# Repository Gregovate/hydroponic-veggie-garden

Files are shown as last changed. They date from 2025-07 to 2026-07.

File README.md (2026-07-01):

# Hydroponics Veggie Garden

A modular hydroponic automation platform built around **ESPHome**, **Home Assistant**, **Node-RED**, and **MariaDB**.

The project has evolved from a simple monitoring controller into a complete hydroponic management system capable of:

* Automated reservoir refill
* Automatic nutrient dosing
* EC monitoring and reference measurements
* Historical event logging
* Seasonal crop management
* Nutrient inventory tracking
* Dashboard-based operation
* Long-term production analysis

The repository contains the firmware, automation workflows, database schema, hardware design, and engineering documentation required to operate, maintain, and rebuild the system.

---

# System Architecture

```text
ESPHome Controller
        │
        ▼
Home Assistant
        │
        ▼
Node-RED
        │
        ▼
MariaDB
        │
        ▼
Dashboard • History • Reporting
```

Each layer has a well-defined responsibility.

* **ESPHome** provides hardware monitoring and low-level control.
* **Home Assistant** provides the operator interface and configuration.
* **Node-RED** performs workflow automation and business logic.
* **MariaDB** stores the permanent operational history.

---

# Standard Operating Procedures (SOP)

Routine operating procedures are located in:

`docs/sop/`

| Procedure | Markdown | Printable PDF |
|---|:---:|:---:|
| Nutrient Solution Mixing | [View](docs/sop/hydroponics-nutrient-solution-mixing.md) | [PDF](docs/sop/hydroponics-nutrient-solution-mixing.pdf) |

---

# Engineering Documentation

The engineering manual is located in the **docs** folder.

| Document | Description |
|---|---|
| [00 – System Overview](docs/00-system-overview.md) | Overall project architecture, system objectives, and engineering philosophy. |
| [01 – Database Design](docs/01-database-design.md) | MariaDB schema, normalization, design rationale, and database architecture. |
| [02 – Season & Layout](docs/02-season-and-layout.md) | Seasonal crop layouts, planting locations, and production planning. |
| [03 – Harvest & Waste Tracking](docs/03-harvest-and-waste-tracking.md) | Harvest recording, waste tracking, and production analysis. |
| [04 – Dashboard & History Design](docs/04-dashboard-history-design.md) | Home Assistant dashboards, Hydro-History browser, and operator workflows. |
| 05 – Nutrient Management & EC Control *(In Development)* | Nutrient management strategy, EC control philosophy, and automatic dosing. |
| 06 – Monitoring & Notification System *(Planned)* | Monitoring strategy, alarms, notifications, and fault handling. |
| 07 – Nutrient Inventory Management *(Planned)* | Dry inventory, stock solutions, batch management, and forecasting. |
| 99 – Disaster Recovery *(Planned)* | Procedures to rebuild the complete system after a major hardware or software failure. |

Additional engineering documents will continue to be added as the project evolves.

---

# Standard Operating Procedures

Routine operating procedures are located in:

```text
docs/sop/
```

Current SOPs include:

* `hydroponics-nutrient-solution-mixing.md`

These documents are intended to be printable field procedures.

---

# Hardware Documentation

Controller and hardware reference documentation is located in:

```text
docs/hardware/
```

Including:

* ESP32 controller
* HX711 calibration
* Alternate pressure sensor
* Voltage divider reference

---

# Repository Layout

```text
credentials/         Local credentials (not committed)

docs/                Engineering documentation
  archive/           Historical documents
  hardware/          Hardware reference
  images/            Documentation images
  sop/               Standard operating procedures

esphome/             ESPHome firmware

hardware/            Bill of materials and enclosure information

home-assistant/
  packages/          Home Assistant packages

node-red/            Production Node-RED flows

schematic/           KiCad schematic and PCB project

sql/                 Database schema and SQL objects
```

---

# Development Philosophy

The project follows a layered architecture.

* Keep hardware logic inside ESPHome.
* Keep operator interaction inside Home Assistant.
* Keep workflow automation inside Node-RED.
* Keep long-term historical data inside MariaDB.

This separation simplifies maintenance, troubleshooting, future expansion, and disaster recovery.

---

# Disaster Recovery

One objective of this repository is complete system reproducibility.

The combination of:

* engineering documentation
* firmware
* Home Assistant packages
* Node-RED flows
* SQL schema
* hardware design files

should allow the hydroponic system to be rebuilt from scratch following a major hardware or software failure.

---

# License

See the `LICENSE` file for licensing information.

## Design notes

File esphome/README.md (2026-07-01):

# ESPHome Controller

Revision: 1.0
Last Updated: 2026-07-01
Status: Production

## Purpose

The ESPHome controller performs the real-time hydroponics control work. It directly interfaces with the sensors, relays, pumps, solenoid, and local controller logic.

Home Assistant and Node-RED supervise and log the system, but the ESPHome controller performs most of the physical control.

## Main File

| File | Purpose |
|---|---|
| `hydroponics-patio-esp32.yaml` | Active ESP32 patio controller firmware. |
| `d1mini.yaml` | Older/monitoring controller reference. |

## Responsibilities

- Read tank volume sensors
- Read water temperature
- Read EC/TDS probe voltage
- Track fill gallons
- Track dose amounts
- Control water fill solenoid
- Control nutrient Pump A
- Control nutrient Pump B
- Expose sensors and switches to Home Assistant
- Provide the physical signals used by Node-RED cycle logging

## Important Entities

| Entity | Purpose |
|---|---|
| `switch.hydroponics_patio_esp32_water_fill_solenoid` | Water fill solenoid control |
| `switch.hydroponics_patio_esp32_nutrient_pump_a` | Nutrient Part A pump |
| `switch.hydroponics_patio_esp32_nutrient_pump_b` | Nutrient Part B pump |
| `sensor.hydroponics_patio_esp32_fill_gallons` | Gallons added during fill |
| `sensor.hydroponics_patio_esp32_dose_a_ml` | Pump A dose volume |
| `sensor.hydroponics_patio_esp32_dose_b_ml` | Pump B dose volume |
| `sensor.hydroponics_patio_esp32_tds_raw` | Raw EC/TDS probe voltage |
| `sensor.hydroponics_patio_esp32_tank_temp` | Tank water temperature |
| `sensor.outside_tank_gallons` | Current tank volume |

## Downstream Consumers

| Consumer | Uses |
|---|---|
| Home Assistant | Dashboard display and control |
| Node-RED Cycle Manager | Watches switch state changes and logs fill/dose events |
| Node-RED TDS Reference | Captures probe voltage, tank volume, and water temperature |
| MariaDB | Stores permanent event and reference history |

## Change Log

| Date | Change |
|---|---|
| 2026-06-28 | Documented ESPHome controller role as the primary physical control layer. |

---

## Related Documentation

- [System Overview](../docs/00-system-overview.md)
- [Database Design](../docs/01-database-design.md)
- [ESP32 Controller Hardware](../docs/hardware/esp_32_controller_readme.md)

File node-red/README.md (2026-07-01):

# Hydroponics Node-RED Workflows

**Revision:** 1.1
**Last Updated:** 2026-07-01
**Status:** Production

---

# Purpose

Node-RED is the workflow automation engine for the hydroponic system.

It receives events from Home Assistant and ESPHome, executes multi-step business logic, validates operational data, and records permanent historical information in MariaDB.

Node-RED coordinates workflows between the operator interface, the ESPHome controller, and the MariaDB database. Physical hardware control remains the responsibility of ESPHome, while Home Assistant provides the primary operator interface.

---

# Responsibilities

Node-RED is responsible for:

- Workflow automation
- Multi-step process execution
- Database transactions
- Hydro-History generation
- Historical event formatting
- MQTT publication
- Business logic
- Operator workflow processing

Node-RED is not responsible for:

- Physical hardware control
- Dashboard presentation
- Long-term data storage

---

## Flow Inventory

| Flow File | Status | Purpose |
| --- | --- | --- |
| `Flow-1_Hydroponics_Cycle_Manager.json`  | ✅ Production | Logs fill/dose maintenance cycles from ESPHome switch activity. |
| `Flow-2_TDS_Reference.json` | ✅ Production | Logs handheld EC/TDS reference checks from the Home Assistant Measure EC popup. |
| `Flow-3_DB_History_Browser.json` | ✅ Production | Retrieves and formats Hydro-History records for Home Assistant. |
| `Flow-4_Add_Note_to_Selected_Event.json` | ✅ Production | Updates operator notes for historical records from supported database sources.  |
| `Flow-5_Insert_Field_Note.json` | ✅ Production | Creates standalone NOTE events with optional date and location metadata. |

---

## Hydroponics Cycle Manager

**Flow File:** `Flow-1_Hydroponics_Cycle_Manager.json`
**Database Target:** `maintenance_log`
**Last Updated:** 2026-06-28

### Purpose

Combines these ESPHome switch events into one maintenance cycle record:

* Water fill solenoid
* Nutrient Pump A
* Nutrient Pump B

### Rules

* Control mode comes from `input_select.hydroponics_outside_control_mode`.
* Control mode is not hardcoded in Node-RED.
* If water was added, the cycle logs as `FILL`.
* If no water was added and nutrient pumps ran, the cycle logs as `DOSE`.
* Fill + dose cycles remain `FILL`.

### 2026-06-28 Repair

Fixed bad logging where an automatic fill-and-dose cycle was incorrectly recorded as:

```text
esp-override DOSE
```

The flow now derives:

```text
mode       = Home Assistant control mode
event_type = physical cycle result
```

---

## TDS / EC Reference

**Flow File:** `Flow-2_TDS_Reference.json`
**Database Target:** `hydro_tds_reference_reading`
**Last Updated:** 2026-06-28

### Purpose

Logs handheld EC/TDS reference checks against the installed probe voltage.

This is a validation check, not a full calibration routine.

### Dashboard Entry Point

Home Assistant button:

```text
Measure EC
```

The popup captures:

* Handheld meter reading
* Meter units
* Note
* Current probe voltage
* Tank gallons
* Water temperature, when available

---

## Hydro-History Browser

**Flow File:** `Flow-3_DB_History_Browser.json`
**Database Target:** `v_hydro_recent_activity`
**Last Updated:** 2026-07-01

### Purpose

Provides the Hydro-History browser displayed in Home Assistant.

The flow retrieves operational history from MariaDB, formats the records for display, and publishes the results to Home Assistant through MQTT.

The browser supports browsing operational history from multiple database sources, creating standalone field notes, and adding operator annotations to existing historical records without requiring manual SQL queries.

### Dashboard Entry Point

Home Assistant History Browser

### Current Features

* State-driven browser updates
* Dynamic records per page
* Dynamic record offset
* Single-record forward/back navigation
* Page forward/back navigation
* Automatic SQL query generation
* MariaDB history retrieval
* MQTT publication to Home Assistant
* Multi-source history browser
* Event selection
* Operator note editing
* Standalone field note creation
* Automatic browser refresh after note save
* Water temperature display for EC reference measurements

### Home Assistant Helpers

* `input_number.hydro_history_record_offset`
* `input_number.hydro_history_records_per_page`
* `input_text.hydro_history_selected_event_id`
* `input_text.hydro_history_operator_note`
* `input_text.hydro_history_field_note`
* `input_datetime.hydro_history_field_note_datetime`
* `input_select.hydro_history_field_note_location`
* `input_button.hydro_history_save_operator_note`
* `input_button.hydro_history_create_field_note`

### MQTT Topic

```text
hydro/history/recent
```

---

## Add Note to Selected Event

**Flow File:** `Flow-4_Add_Note_to_Selected_Event.json`

**Database Targets:** `maintenance_log`, `hydro_tds_reference_reading`

**Last Updated:** 2026-07-01

### Purpose

Updates operator annotations for existing Hydro-History records.

The flow determines the source table from the selected source-aware event identifier and updates the appropriate database record.

This allows historical events from multiple database tables to be annotated from a single Home Assistant interface.

### Dashboard Entry Point

Home Assistant History Browser

### Current Features

* Reads selected source-aware event identifier
* Reads operator note from Home Assistant
* Updates `maintenance_log.operator_note`
* Updates `hydro_tds_reference_reading.operator_note`
* Clears operator note helper after save
* Automatically refreshes the Hydro-History browser

### Home Assistant Helpers

* `input_text.hydro_history_selected_event_id`
* `input_text.hydro_history_operator_note`
* `input_button.hydro_history_save_operator_note`

### Supported Record Sources

* `maintenance_log`
* `hydro_tds_reference_reading`

---

## Insert Field Note

**Flow File:** `Flow-5_Insert_Field_Note.json`

**Database Target:** `maintenance_log`

**Last Updated:** 2026-07-01

### Purpose

Creates standalone field notes that are stored as `NOTE` events in the `maintenance_log` table.

Unlike operator notes, field notes create a new historical record that can document observations, maintenance activities, weather conditions, equipment issues, or other operational events not associated with an existing history record.

### Dashboard Entry Point

Home Assistant History Browser

### Current Features

* Creates standalone `NOTE` events
* Optional event date override
* Optional location selection
* Uses current save time for timestamp
* Stores notes in `maintenance_log`
* Clears helper entities after save
* Automatically refreshes the Hydro-History browser

### Home Assistant Helpers

* `input_text.hydro_history_field_note`
* `input_datetime.hydro_history_field_note_datetime`
* `input_select.hydro_history_field_note_location`
* `input_button.hydro_history_create_field_note`

### Default Values

| Field | Default |
| ----- | --- |
| Source | `outside` |
| Device | `home_assistant` |
| Event Type | `NOTE` |
| Mode | `manual` |

---

# Planned Workflows

* Equipment issue workflow
* Maintenance completed workflow
* Event detail popup
* History filtering
* Search

---

# Revision History

| Date | Flow | Change |
| --- | --- | --- |
| 2026-07-01 | `Flow-5_Insert_Field_Note.json` | Initial production workflow. Added standalone field note creation with optional event date, location selection, automatic helper clearing, and Hydro-History browser refresh. |
| 2026-07-01 | `Flow-4_Add_Note_to_Selected_Event.json`| Initial production workflow. Added source-aware operator note updates supporting both `maintenance_log` and `hydro_tds_reference_reading`, automatic helper clearing, and Hydro-History browser refresh. |
| 2026-07-01 | `Flow-3_DB_History_Browser.json` | Completed Hydro-History browser. Added multi-source history support, source-aware event selection, EC reference integration, water temperature display, standalone field note support, and browser refresh improvements. |
| 2026-06-29 | `Flow-3_DB_History_Browser.json` | Initial Hydro-History browser. Added state-driven paging using Home Assistant helpers, MariaDB query of `v_hydro_recent_activity`, formatting, and MQTT publication for dashboard display. |
| 2026-06-28 | `Flow-1_Hydroponics_Cycle_Manager.json` | Repaired mode/event logging. Mode now comes from Home Assistant control mode. Fill+dose cycles log as `FILL`. |
| 2026-06-28 | `Flow-2_TDS_Reference.json` | Added production EC reference capture workflow from the Home Assistant Measure EC popup to MariaDB. |

---

# Navigation

## Engineering Manual

- [System Overview](../docs/00-system-overview.md)
- [Dashboard & History Design](../docs/04-dashboard-history-design.md)
- [Nutrient Management & EC Control](../docs/05-nutrient-management-and-ec-control.md)

## Component Documentation

- [ESPHome](../esphome/README.md)
- [Home Assistant Packages](../home-assistant/packages/README.md)
- [SQL](../sql/README.md)

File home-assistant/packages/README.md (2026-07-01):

# Home Assistant Packages

**Revision:** 1.1
**Last Updated:** 2026-07-01
**Status:** Production

---

# Purpose

Home Assistant is the supervisory and operator interface for the hydroponics system.

While the ESPHome controller performs most real-time control of the hardware, Home Assistant provides:

* Operator dashboards
* User controls
* Helper entities
* Configuration values
* Scripts
* SQL sensors
* Database integration
* User notifications
* Integration with Node-RED workflows

Home Assistant acts as the interface between the operator, the ESPHome controller, Node-RED, and the MariaDB database.

---

# System Architecture

```text
                    Operator
                        │
                        ▼
             Home Assistant Dashboard
                        │
        ┌───────────────┼───────────────┐
        │               │               │
        ▼               ▼               ▼
   Helper Entities   Scripts/UI     SQL Sensors
        │               │               │
        └───────────────┼───────────────┘
                        │
                        ▼
                   Node-RED
                Workflow Engine
                        │
                        ▼
                    MariaDB
                        ▲
                        │
                  ESPHome Controller
                        │
                        ▼
                 Physical Hardware
```

---

# System Ownership

| Item | Owner | Notes |
| --- | --- | --- |
| Physical sensors | ESPHome | Direct hardware interface |
| Pump and solenoid control | ESPHome | Real-time hardware control |
| Raw HX711 value | ESPHome | Load cell amplifier reading |
| Tank gallons | Home Assistant | Calculated from HX711 calibration points |
| Control mode | Home Assistant | Auto / Manual / ESP-Override |
| Dashboard helper entities | Home Assistant | Input helpers, scripts, SQL sensors and UI state |
| Workflow automation | Node-RED | Multi-step workflow execution and database logging |
| Maintenance history | MariaDB | `maintenance_log` |
| EC reference history | MariaDB | `hydro_tds_reference_reading` |
| Inventory | MariaDB | Purchases, batches and stock solutions |
| Harvest history | MariaDB | Seasonal production records |

---

# Package Inventory

| Package | Purpose | Status |
|---|---|:---:|
| `global_constants.yaml` | Shared constants used throughout the Home Assistant packages. | ✅ Production |
| `patio_system_constants.yaml` | Outdoor hydroponics system configuration and operating constants. | ✅ Production |
| `patio_controller.yaml` | Primary controller helpers, scripts, template sensors, and dashboard entities. | ✅ Production |
| `patio_dosing_controls.yaml` | Nutrient dosing controls, automatic dosing helpers, and Measure EC workflow support. | ✅ Production |
| `patio_energy_monitoring.yaml` | Electrical monitoring and power consumption. | ✅ Production |
| `db_connect.yaml` | SQL integration and MariaDB connection configuration. | ✅ Production |
| `db_history_dashboard.yaml` | Hydro-History dashboard entities and browser support. | ✅ Production |
| `batch_building.yaml` | Helper entities for nutrient batch creation and inventory workflows. | 🚧 Partial |
| `harvest_inputs.yaml` | Helper entities for seasonal harvest and waste workflows. | 🚧 Partial |
| `obsolete/` | Historical package versions retained for reference only. | ❌ Legacy |

---

# Responsibilities

Home Assistant serves as the supervisory control system and primary operator interface for the hydroponic vegetable garden.

Its responsibilities include:

---

## Operator Interface

Provide the primary interface for day-to-day operation.

Examples:

* System status dashboards
* Controller mode selection
* Manual controls
* Dashboard workflows
* Notifications
* System configuration
* System health

---

## Monitoring

Display current operating conditions.

Examples:

* Reservoir volume
* Probe voltage
* Estimated EC
* Water temperature
* Flow rates
* Fill status
* Dosing status
* Controller status
* Energy monitoring

---

## Operator Workflows

Provide user entry points into production workflows.

Current workflows include:

* Measure EC
* Hydro-History Browser
* Event annotation
* Standalone field notes

Planned workflows include:

* Nutrient batch creation
* Inventory updates
* Harvest entry
* Waste entry

---

## Helper Entities

Provide configurable values without modifying ESPHome firmware.

Examples include:

* Controller mode
* HX711 calibration points
* Target EC
* Fill thresholds
* Dashboard state
* Batch helper values
* Harvest helper values

---

## Scripts

Provide reusable dashboard actions.

Examples include:

* Measure EC
* Event annotation
* Field note entry
* Batch-building workflow
* Harvest workflow

---

## SQL Integration

Retrieve historical information from MariaDB for dashboard presentation.

Examples include:

* Recent activity
* Inventory status
* Event details
* Production statistics
* Future harvest summaries

---

## Node-RED Integration

Provide helper entities and workflow entry points used by Node-RED.

Examples include:

* Control mode
* Dashboard workflow triggers
* Measure EC
* History Browser
* Batch building
* Harvest entry

Node-RED executes workflow automation and writes permanent records to MariaDB.

---

## UI Automations

Some automations currently remain in the Home Assistant UI for:

* Testing
* Trace debugging
* Experimental workflows

Production automations should be migrated into package YAML or Node-RED whenever practical.

---

# Documentation Maintenance

This README describes the current Home Assistant package architecture.

Update this document whenever changes affect:

- Package organization
- Package responsibilities
- Helper entities
- Dashboard workflows
- SQL sensors
- Node-RED integration
- Production automations
- Package dependencies
- System ownership

Routine dashboard layout or cosmetic UI changes do not require updates unless they change system behavior or operator workflows.

---

# Revision History

| Date | Revision | Description |
|---|:---:|---|
| 2026-07-01 | 1.1 | Updated package inventory, added Hydro-History package, revised responsibilities, added navigation, and synchronized documentation with the current repository structure. |
| 2026-06-28 | 1.0 | Initial Home Assistant package architecture documentation. |

---

# Navigation

## Engineering Manual

- [System Overview](../../docs/00-system-overview.md)
- [Database Design](../../docs/01-database-design.md)
- [Dashboard & History Design](../../docs/04-dashboard-history-design.md)

## Component Documentation

- [ESPHome](../../esphome/README.md)
- [Node-RED](../../node-red/README.md)
- [SQL](../../sql/README.md)

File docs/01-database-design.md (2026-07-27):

# Hydroponics Database Design

**Revision:** 0.4
**Last Updated:** 2026-07-22
**Status:** Active Reference / Partial Implementation
---

# Purpose

The Hydroponics database is the permanent record for the outdoor hydroponic vegetable system.

This document identifies:

* What database objects currently exist
* What each object is used for
* What fields are available
* What writes data to each table
* What reads data from each table
* Which objects are production, partial, planned, or legacy

This document is the database reference.

Workflow implementation details belong in:

* `node-red/README.md`
* `home-assistant/packages/README.md`
* `docs/04-dashboard-history-design.md`

---

# Timestamp Standard

All operational timestamps in the Hydroponics database are stored in **local system time**.

The system is designed for a single physical installation and all history is viewed by the local operator.

Reasons:

- Simplifies SQL queries (`TODAY`, `THIS WEEK`, etc.)
- Dashboard times match the database without conversion
- Correlates directly with maintenance activities, photographs, weather, and inspection notes
- Eliminates unnecessary timezone conversions

UTC timestamps are not used within the Hydroponics database.

If cloud synchronization or multi-site support is implemented in the future, UTC conversion will occur during export rather than storage.

---

# Status Definitions

| Status | Meaning |
| --- | --- |
| ✅ Production | Used during normal operation. |
| 🚧 Partial | Object exists and may contain useful data, but workflow is incomplete. |
| 🧱 Database Only | Schema exists, but no finished operator workflow exists. |
| ⏳ Planned | Designed for a future workflow. |
| ❌ Legacy | Retained only for historical reference or migration review. |

---

# Current Production Workflows

| Workflow | Status | Writes To | Started From |
| --- | --- | --- | --- |
| Fill / Dose Cycle Logging | ✅ Production | `maintenance_log` | ESPHome switch activity through Node-RED |
| EC / TDS Reference Measurement | ✅ Production | `hydro_tds_reference_reading` | Home Assistant Measure EC popup through Node-RED |

---

# Current Object Inventory

## Base Tables

| Table | Status | Purpose |
| --- | --- | --- |
| `maintenance_log` | ✅ Production  | Primary operational event history for fill and dose cycles. |
| `hydro_tds_reference_reading` | ✅ Production  | Handheld EC/TDS meter checks compared to installed probe voltage. |
| `ingredients` | 🚧 Partial | Master list of dry nutrient ingredients. |
| `purchases` | 🚧 Partial | Purchase header records. |
| `purchase_items` | 🚧 Partial | Purchased ingredient line items. |
| `inventory_ledger` | 🚧 Partial | Inventory movement history. |
| `nutrient_batches` | 🚧 Partial | Nutrient stock batch headers. |
| `nutrient_batch_items` | 🚧 Partial | Ingredients used in each nutrient batch. |
| `nutrient_stock_solution` | 🚧 Partial | Part A / Part B stock solution containers. |
| `hydro_season` | ✅ Implemented | Growing season records. |
| `hydro_position` | ✅ Production  | Permanent growing positions (E1–E7 and W1–W6). |
| `hydro_crop` | ✅ Implemented | Master list of crop types (Tomato, Pepper, Eggplant, etc.). |
| `crop_variety` | ✅ Implemented | Crop variety master list linked to a crop type. |
| `hydro_season_planting` | ✅ Implemented | Assigns a crop variety to a permanent position for a growing season. |
| `hydro_harvest` | ✅ Implemented | Harvest records linked to the originating planting assignment. |
| `hydro_waste` | ✅ Implemented | Waste and crop loss records linked to the originating planting. |
| `stg_maintenance_csv` | ❌ Legacy | CSV import staging table. |
| `purchases_legacy` | ❌ Legacy | Earlier purchase table. |
| `dry_chem_purchases_legacy` | ❌ Legacy | Earlier dry chemical purchase table. |
| `nutrient_batches_legacy` | ❌ Legacy | Earlier nutrient batch table. |

## Views

| View | Status | Purpose |
| --- | --- | --- |
| `v_hydro_recent_activity` | ✅ Production / New | Timeline view combining maintenance events and EC reference readings. |
| `v_inventory_current` | 🚧 Partial | Current inventory quantity by ingredient. |
| `v_inventory_low` | 🚧 Partial | Low inventory warning view. |
| `v_inventory_ledger_detail`  | 🚧 Partial | Inventory transaction detail. |
| `v_ingredient_inventory` | 🚧 Partial | Ingredient inventory summary. |
| `v_remaining_batch_capacity` | 🚧 Partial | Estimated nutrient batches possible from remaining dry stock. |
| `v_purchase_costs_ytd` | 🚧 Partial | Year-to-date purchase costs. |
| `v_unit_cost_per_item_ytd` | 🚧 Partial | Unit cost calculations. |
| `v_batch_recipe` | 🚧 Partial | Nutrient batch recipe detail. |
| `v_nutrient_batches_detail`  | 🚧 Partial | Nutrient batch detail. |
| `v_harvests` | ⏳ Planned / Legacy Dependent | Harvest reporting view. |
| `v_harvest_summary_ytd` | ⏳ Planned / Legacy Dependent | Year-to-date harvest summary. |
| `dry_chem_purchases` | ❌ Legacy View | Old dry chemical purchase view. |
| `hydroponics_outside` | ❌ Broken Legacy View | Old view over maintenance data. Do not use. |

---

# Active Production Tables

## `maintenance_log`

**Status:** ✅ Production
**Purpose:** Primary operational event history.
**Written By:** Node-RED `Hydroponics_Cycle_Manager.json`
**Read By:** `v_hydro_recent_activity`, future history dashboard.

### Important Rule

`maintenance_log` is the active production event table.

`hydroponics_outside_events` was dropped and is no longer part of the active schema.

### Design Notes

`maintenance_log` records completed operational events for the hydroponics
controller.

Each record captures the controller state at the time the event occurred,
including water movement, nutrient additions, and engineering measurements.

Beginning with the dual-probe measurement architecture, the table stores both
raw and filtered voltages for each analog probe channel. The handheld EC meter
remains the engineering reference standard and is recorded separately in
`hydro_tds_reference_reading`.

### Columns

| Column | Type | Notes |
|---|---|---|
| `id` | int auto_increment | Primary key |
| `timestamp_utc` | datetime | UTC event timestamp (legacy compatibility) |
| `internal_time` | datetime | Local event timestamp used by dashboards |
| `source` | varchar(32) | Usually `outside` |
| `location` | varchar(64) | Usually `patio` |
| `crop` | varchar(32) | Reserved for future use |
| `variety` | varchar(64) | Reserved for future use |
| `device` | varchar(64) | Source device or workflow |
| `event_type` | enum | `FILL`, `DOSE`, `BATCH`, `PURCHASE`, `NOTE`, `HARVEST`, `ALERT` |
| `mode` | varchar(32) | Controller operating mode |
| `system_gallons` | float | System volume when event began |
| `gallons_added` | float | Water added during fill |
| `dose_a_ml` | float | Nutrient Part A added |
| `dose_b_ml` | float | Nutrient Part B added |
| `a0_raw_v_before` | float | A0 raw voltage before event |
| `a0_filtered_v_before` | float | A0 filtered voltage before event |
| `a1_raw_v_before` | float | A1 raw voltage before event |
| `a1_filtered_v_before` | float | A1 filtered voltage before event |
| `a0_raw_v_after` | float | A0 raw voltage after event |
| `a0_filtered_v_after` | float | A0 filtered voltage after event |
| `a1_raw_v_after` | float | A1 raw voltage after event |
| `a1_filtered_v_after` | float | A1 filtered voltage after event |
| `ec_before` | float | Reserved for future calculated EC |
| `ec_after` | float | Reserved for future calculated EC |
| `plant` | varchar(64) | Reserved for future use |
| `harvest_weight_g` | float | Harvest logging |
| `harvest_count` | int | Harvest logging |
| `harvest_unit` | varchar(16) | Default `item` |
| `cost_usd` | decimal(12,2) | Reserved for future use |
| `note` | text | Automatic event summary generated by Node-RED |
| `operator_note` | text | Optional operator-entered note |
| `raw_message` | text | Raw workflow payload retained for diagnostics |

### Indexes

| Index | Column |
|---|---|
| `PRIMARY` | `id` |
| `idx_ml_timestamp` | `timestamp_utc` |
| `idx_ml_source` | `source` |
| `idx_ml_location` | `location` |
| `idx_ml_event_type` | `event_type` |
| `idx_ml_crop` | `crop` |
| `idx_ml_variety` | `variety` |

### Voltage Measurement Fields

Beginning with the dual-probe engineering architecture, `maintenance_log`
stores independent measurements for each analog input channel.

Current assignments are:

| Channel | Current Assignment |
|---|---|
| **A0** | Original KEYESTUDIO analog probe |
| **A1** | DFRobot Gravity analog probe |

Each channel records both:

- Raw voltage (direct ADC measurement)
- Filtered voltage (used for controller operation and dashboard display)

For events that include post-event measurements (such as automatic fill),
both **Before** and **After** values are recorded.

Events that do not perform a delayed post-event measurement (such as individual
ESP-Override doses) may leave the **After** fields `NULL`.

### Event Notes

`maintenance_log` contains two note fields with different purposes.

#### `note`

Automatically generated by the Hydroponics Cycle Manager.

This field summarizes what occurred during the event and should normally not be edited.

Examples:

- auto FILL: added 5.11 gal water; dose A 51 mL; dose B 51 mL...
- esp-override DOSE: dose A 10 mL...
- manual NOTE: engineering observation...

#### `operator_note`

Optional operator comment added after the event.

Typical uses include:

- equipment failures
- wasted fills
- sensor problems
- calibration observations
- unusual operating conditions

Most events will have a `NULL` `operator_note`.

Example:

```text
Fill wasted due to broken recirculating pump hose clamp. Nutrients discharged
onto the patio instead of remaining in the reservoir.
```

---

## `hydro_tds_reference_reading`

**Status:** ✅ Production
**Purpose:** Stores handheld EC reference measurements synchronized with analog
probe voltages and operating conditions for calibration and engineering analysis.
**Written By:** Node-RED `TDS_Reference.json`
**Started From:** Home Assistant Measure EC popup
**Read By:** `v_hydro_recent_activity`, future EC reference dashboard.

### Design Notes

The handheld EC meter is the engineering reference standard.

Each record captures a synchronized snapshot of:

- Handheld EC measurement
- Analog probe voltages (A0 and A1)
- Water temperature
- Tank volume
- Rainfall and estimated dilution

These records are used to evaluate probe performance, develop EC estimation
models, and validate future automatic dosing algorithms.

### Handheld EC Recording Convention

The handheld reference instrument is a Bluelab Truncheon conductivity meter.

The Truncheon displays EC in discrete **0.2 EC increments** using illuminated
LEDs rather than a continuous numeric display.

To preserve additional resolution during engineering calibration:

- **Even-tenth values** (1.8, 2.0, 2.2, etc.) indicate a stable Truncheon LED
  at that EC value.

- **Odd-tenth values** (1.9, 2.1, 2.3, etc.) indicate the Truncheon was
  alternating between the adjacent even EC values and the midpoint was recorded
  by the operator.

Examples:

| Stored Value | Truncheon Indication |
|---|---|
| 1.8 | Stable at 1.8 EC |
| 1.9 | Alternating between 1.8 and 2.0 EC |
| 2.0 | Stable at 2.0 EC |
| 2.1 | Alternating between 2.0 and 2.2 EC |

This convention preserves additional engineering information without requiring
an additional database field and should be considered when evaluating EC
calibration data.

### Columns

| Column | Type | Notes |
|---|---|---|
| `id` | bigint auto_increment | Primary key |
| `captured_at` | datetime | Local reading timestamp |
| `system_key` | varchar(50) | Default `outside` |
| `a0_raw_v` | decimal(6,3) | A0 raw voltage |
| `a0_filtered_v` | decimal(6,3) | A0 filtered voltage |
| `a1_raw_v` | decimal(6,3) | A1 raw voltage |
| `a1_filtered_v` | decimal(6,3) | A1 filtered voltage |
| `meter_value` | decimal(8,2) | decimal(8,2) | Handheld EC reference. Even-tenth values indicate a stable Truncheon reading; odd-tenth values indicate midpoint interpolation between alternating adjacent LEDs. |
| `meter_units` | varchar(20) | Usually `EC` |
| `tank_gallons` | decimal(8,2) | Tank volume at measurement |
| `water_temp_f` | decimal(6,2) | Water temperature |
| `rain_total_in` | decimal(8,3) | Cumulative rainfall |
| `rain_since_last_reference_in` | decimal(8,3) | Rain since previous EC reference |
| `estimated_rain_added_gal` | decimal(8,3) | Estimated rainwater added |
| `note` | varchar(255) | Note entered during EC measurement |
| `operator_note` | varchar(255) | Later engineering annotation |

### Indexes

| Index | Column |
|---|---|
| `PRIMARY` | `id` |

### Analog Measurement Channels

Current channel assignments:

| Channel | Assignment |
|---|---|
| **A0** | Original KEYESTUDIO analog probe |
| **A1** | DFRobot Gravity analog probe |

Each EC reference captures both the raw ADC voltage and the filtered operating
voltage for each channel.

The filtered values are used by dashboards and engineering analysis, while the
raw values are retained for sensor characterization and future filter
development.

### Rainfall / Dilution Context

Rainfall can dilute the outdoor reservoir because part of the tank is exposed.

Each EC reference records cumulative rainfall at the time of the handheld
measurement. It also calculates rainfall since the previous EC reference and
estimates the amount of rainwater that entered the reservoir.

This allows EC reference measurements to be evaluated together with:

- handheld EC (engineering reference)
- A0 raw and filtered voltage
- A1 raw and filtered voltage
- water temperature
- tank volume
- rainfall since the previous EC reference
- estimated rainwater dilution

The estimated rain volume is calculated from the exposed tank opening defined
in the Home Assistant patio system constants.
---

## `purchases`

**Status:** 🚧 Partial
**Purpose:** Purchase header records for dry ingredients and supplies.
**Written By:** Manual SQL / future purchase workflow.
**Read By:** Purchase cost and inventory workflows.

### Columns

| Column | Type | Notes |
| --- | --- | --- |
| `purchase_id` | int auto_increment | Primary key |
| `order_number` | varchar(50) | Order number |
| `purchase_date` | date | Purchase date |
| `vendor` | varchar(100) | Default `Amazon` |
| `total_price_usd` | decimal(10,2) | Total purchase cost |
| `notes` | text | Notes |
| `created_at` | timestamp | Created timestamp |

### Indexes

| Index | Column |
| --- | --- |
| `PRIMARY` | `purchase_id` |

---

## `purchase_items`

**Status:** 🚧 Partial
**Purpose:** Purchased ingredient line items.
**Written By:** Manual SQL / future purchase workflow.
**Read By:** Inventory ledger and purchase cost views.

### Columns

| Column | Type | Notes |
| --- | --- | --- |
| `purchase_item_id` | int auto_increment | Primary key |
| `purchase_id` | int | Links to `purchases` |
| `ingredient_id` | int | Links to `ingredients` |
| `quantity_lb` | decimal(10,3) | Quantity in pounds |
| `quantity_g` | decimal(10,2) | Quantity in grams |
| `item_price_usd` | decimal(10,2) | Item cost |
| `notes` | text | Notes |
| `created_at` | timestamp | Created timestamp |

### Indexes

| Index | Column |
| --- | --- |
| `PRIMARY` | `purchase_item_id` |
| `purchase_id` | `purchase_id` |
| `ingredient_id` | `ingredient_id` |

---

## `inventory_ledger`

**Status:** 🚧 Partial
**Purpose:** Tracks dry ingredient inventory changes over time.
**Written By:** Manual SQL / future purchase, batch, and adjustment workflows.
**Read By:** Inventory views.

### Columns

| Column | Type | Notes |
| --- | --- | --- |
| `ledger_id` | int auto_increment | Primary key |
| `ledger_date` | date | Ledger event date |
| `ingredient_id` | int | Links to `ingredients` |
| `event_type` | enum | `PURCHASE`, `BATCH_USE`, `RECONCILIATION` |
| `source_table`  | varchar(50) | Source object name |
| `source_id` | int | Source record id |
| `delta_g` | decimal(10,2) | Inventory increase/decrease in grams |
| `notes` | text | Notes |
| `created_at` | timestamp | Created timestamp |

### Indexes

| Index | Column |
| --- | --- |
| `PRIMARY` | `ledger_id` |
| `ingredient_id` | `ingredient_id` |

---

## `nutrient_batches`

**Status:** 🚧 Partial
**Purpose:** Nutrient stock solution batch header.
**Written By:** Manual SQL / future batch-building workflow.
**Read By:** Nutrient batch views and stock solution tracking.

### Columns

| Column | Type | Notes |
| --- | --- | --- |
| `batch_id` | int auto_increment | Primary key |
| `batch_code` | varchar(50) | Unique batch code |
| `batch_date` | date | Batch date |
| `batch_part` | enum | `A` or `B` |
| `final_volume_ml` | decimal(10,2) | Default `3785.00` |
| `notes` | text | Notes |
| `created_at` | timestamp | Created timestamp |

### Indexes

| Index | Column |
| --- | --- |
| `PRIMARY` | `batch_id` |
| `batch_code` | `batch_code` |

---

## `nutrient_batch_items`

**Status:** 🚧 Partial
**Purpose:** Ingredients used in each nutrient batch.
**Written By:** Manual SQL / future batch-building workflow.
**Read By:** Batch recipe and inventory workflows.

### Columns

| Column | Type | Notes |
| --- | --- | --- |
| `batch_item_id` | int auto_increment | Primary key |
| `batch_id` | int | Links to `nutrient_batches` |
| `ingredient_id` | int | Links to `ingredients` |
| `quantity_g` | decimal(10,2) | Quantity used |
| `notes` | text | Notes |
| `created_at` | timestamp | Created timestamp |

### Indexes

| Index | Column |
| --- | --- |
| `PRIMARY` | `batch_item_id` |
| `batch_id` | `batch_id` |
| `ingredient_id` | `ingredient_id` |

---

## `nutrient_stock_solution`

**Status:** 🚧 Partial
**Purpose:** Tracks Part A and Part B stock solution container volumes.
**Written By:** Manual SQL / future batch-building and top-off workflows.
**Read By:** Future inventory and dosing dashboards.

### Columns

| Column | Type | Notes |
| --- | --- | --- |
| `stock_solution_id`  | int auto_increment | Primary key |
| `stock_part` | enum | `A` or `B` |
| `created_date` | date | Created date |
| `source_batch_code`  | varchar(50) | Source batch |
| `starting_volume_ml` | decimal(10,2) | Starting volume |
| `current_volume_ml`  | decimal(10,2) | Current volume |
| `status` | enum | `ACTIVE`, `EMPTY`, `ARCHIVED` |
| `notes` | text | Notes |
| `created_at` | timestamp | Created timestamp |

### Indexes

| Index | Column |
| --- | --- |
| `PRIMARY` | `stock_solution_id` |

---

# Season, Planting, Harvest, and Waste Tables

## `hydro_season`

**Status:** ⏳ Planned  
**Purpose:** Defines growing seasons.  
**Written By:** Future season setup workflow.  
**Read By:** Planting, harvest, waste, and production reports.

### Columns

| Column | Type | Notes |
|---|---|---|
| `season_id` | int auto_increment | Primary key |
| `system_key` | varchar(50) | Default `outside` |
| `season_year` | int | Season year |
| `season_name` | varchar(100) | Display name |
| `start_date` | date | Start date |
| `end_date` | date | End date |
| `status` | enum | `planned`, `active`, `closed`, `archived` |
| `notes` | text | Notes |
| `created_at` | datetime | Created timestamp |

### Indexes

| Index | Column |
|---|---|
| `PRIMARY` | `season_id` |
| `uq_hydro_season` | `system_key`, `season_year` |

---

## `hydro_position`

**Status:** ✅ Production  
**Purpose:** Defines the permanent physical growing positions within the hydroponics system. Position records are independent of growing seasons and remain constant over time.  
**Written By:** Initial system configuration.  
**Read By:** Season planting, harvest, waste, dashboards, and production reporting.

### Columns

| Column | Type | Notes |
|---|---|---|
| `position_id` | int auto_increment | Primary key |
| `system_key` | varchar(50) | Hydroponic system identifier. Default `outside`. |
| `channel` | varchar(20) | Growing channel (`East` or `West`) |
| `position_code` | varchar(10) | Permanent position identifier (E1–E7, W1–W6) |
| `position_number` | int | Position number within the channel |
| `flow_order` | int | Order of nutrient flow through the channel |
| `active` | tinyint(1) | Active position flag |
| `notes` | text | Optional notes |

### Relationships

Referenced by:

- `hydro_season_planting.position_id`

### Indexes

| Index | Type | Columns |
|---|---|---|
| `PRIMARY` | Primary Key | `position_id` |
| `uq_hydro_position` | Unique | `system_key`, `position_code` |

### Business Rules

- Position identifiers are permanent and never change.
- A position may participate in many growing seasons over time.
- Physical positions are assigned to seasons through `hydro_season_planting`.

---

## `hydro_crop`

**Status:** ✅ Implemented  
**Purpose:** Master list of supported crop types.  
**Written By:** Crop management workflow.  
**Read By:** Crop variety management, planting, harvest, waste, and production reporting.

### Columns

| Column | Type | Notes |
|---|---|---|
| `crop_id` | int auto_increment | Primary key |
| `crop_name` | varchar(50) | Crop type (Tomato, Pepper, Eggplant, etc.) |
| `active` | tinyint(1) | Active crop flag |
| `notes` | text | Optional notes |
| `created_at` | datetime | Record creation timestamp |

### Relationships

Referenced by:

- `crop_variety.crop_id`

### Indexes

| Index | Type | Columns |
|---|---|---|
| `PRIMARY` | Primary Key | `crop_id` |
| `uq_hydro_crop_name` | Unique | `crop_name` |

---

## `crop_variety`

**Status:** ✅ Implemented  
**Purpose:** Stores reusable crop varieties associated with a crop type.  
**Written By:** Crop management workflow.  
**Read By:** Season planting, harvest, waste, and production reporting.

### Columns

| Column | Type | Notes |
|---|---|---|
| `variety_id` | int auto_increment | Primary key |
| `crop_id` | int | References `hydro_crop` |
| `variety_name` | varchar(100) | Variety or cultivar name |
| `seed_source` | varchar(100) | Optional seed supplier or source |
| `notes` | text | Optional notes |
| `active` | tinyint(1) | Active variety flag |
| `created_at` | datetime | Record creation timestamp |

### Relationships

References:

- `hydro_crop.crop_id`

Referenced by:

- `hydro_season_planting.variety_id`

### Indexes

| Index | Type | Columns |
|---|---|---|
| `PRIMARY` | Primary Key | `variety_id` |
| `uq_crop_variety_crop_name` | Unique | `crop_id`, `variety_name` |
| `fk_crop_variety_crop` | Foreign Key | `crop_id` |

---

## `hydro_season_planting`

**Status:** ✅ Implemented  
**Purpose:** Assigns a crop variety to a permanent growing position for a specific growing season. This table forms the central relationship between seasons, positions, and crops.  
**Written By:** Planting workflow.  
**Read By:** Harvest, waste, dashboards, history, and production reporting.

### Columns

| Column | Type | Notes |
|---|---|---|
| `planting_id` | int auto_increment | Primary key |
| `season_id` | int | References `hydro_season` |
| `position_id` | int | References `hydro_position` |
| `variety_id` | int | References `crop_variety`; `NULL` for empty positions |
| `plant_count` | int | Number of plants at this position |
| `planted_date` | date | Planting date |
| `removed_date` | date | Removal date |
| `status` | enum | `planned`, `planted`, `removed`, `failed`, `empty` |
| `notes` | text | Optional notes |
| `created_at` | datetime | Record creation timestamp |

### Relationships

References:

- `hydro_season.season_id`
- `hydro_position.position_id`
- `crop_variety.variety_id`

Referenced by:

- `hydro_harvest.planting_id`
- `hydro_waste.planting_id`

### Indexes

| Index | Type | Columns |
|---|---|---|
| `PRIMARY` | Primary Key | `planting_id` |
| `uq_hydro_season_position` | Unique | `season_id`, `position_id` |
| `fk_hydro_planting_position` | Foreign Key | `position_id` |
| `fk_hydro_planting_variety` | Foreign Key | `variety_id` |

### Business Rules

- Each physical position receives one planting assignment per growing season.
- Empty positions are represented by `status = 'empty'`, `variety_id = NULL`, and `plant_count = 0`.
- Harvest and waste records always reference the planting assignment rather than storing crop, variety, season, or position independently.

---

## `hydro_harvest`

**Status:** ✅ Production  
**Purpose:** Records harvested produce from a planting assignment. Multiple harvests may be recorded for the same planting throughout the growing season.  
**Written By:** Node-RED Harvest workflow.  
**Read By:** Hydro-History, harvest reporting, production analysis, and future cost analysis.

### Columns

| Column | Type | Notes |
|---|---|---|
| `harvest_id` | int auto_increment | Primary key |
| `planting_id` | int | Required reference to `hydro_season_planting.planting_id` |
| `harvested_at` | datetime | Local harvest timestamp; defaults to the local database time |
| `harvest_count` | int nullable | Optional quantity harvested; stored as `NULL` when count was not entered |
| `harvest_unit` | varchar(20) | Unit associated with `harvest_count`; currently defaults to `item` |
| `total_weight` | decimal(10,3) nullable | Optional total harvested weight; stored as entered by the operator |
| `weight_unit` | enum | Operator-selected weight unit (lb, oz, g, kg); always populated |
| `quality` | enum nullable | Harvest classification: `good`, `mixed`, `poor`, or `waste`; the current Harvest workflow writes `good` |
| `notes` | text nullable | Optional operator note |
| `created_at` | datetime | Local record-creation timestamp; defaults to the local database time |

### Relationships

References:

- `hydro_season_planting.planting_id`

Foreign-key behavior:

- Updates to `planting_id` cascade to related harvest records.
- A planting assignment cannot be deleted while harvest records reference it.

### Indexes

| Index | Type | Columns |
|---|---|---|
| `PRIMARY` | Primary Key | `harvest_id` |
| `idx_hydro_harvest_planting` | Index | `planting_id` |
| `idx_hydro_harvest_date` | Index | `harvested_at` |

### Constraints

| Constraint | Type | Columns |
|---|---|---|
| `fk_hydro_harvest_planting` | Foreign Key | `planting_id` → `hydro_season_planting.planting_id` |

### Business Rules

- Every harvest belongs to one planting assignment.
- A planting may have multiple harvest records.
- Season, position, crop, and variety are derived through the planting assignment.
- Harvest count and harvest weight are independently optional.
- At least one of `harvest_count` or `total_weight` must be greater than zero before the workflow permits an insert.
- `harvest_unit` applies only to `harvest_count`.
- `weight_unit` applies only to `total_weight`.
- Harvest weight is stored in the unit selected by the operator; the workflow does not convert the value before insertion.
- `weight_unit` is always populated, even when `total_weight` is `NULL`, so the record has a defined unit if weight is added or edited later.
- The Harvest dashboard retains the last-selected weight unit after submission while clearing the planting, count, weight, and note fields.
- All operational timestamps are stored in local system time.

---

## `hydro_waste`

**Status:** ✅ Implemented  
**Purpose:** Records plant material or produce removed without being counted as harvested production.  
**Written By:** Waste tracking workflow.  
**Read By:** Waste reporting and production analytics.

### Columns

| Column | Type | Notes |
|---|---|---|
| `waste_id` | int auto_increment | Primary key |
| `planting_id` | int | References `hydro_season_planting` |
| `wasted_at` | datetime | Waste timestamp |
| `waste_type` | enum | Classified waste reason |
| `waste_count` | int | Quantity discarded |
| `waste_weight` | decimal(10,3) | Total discarded weight |
| `weight_unit` | enum | `lb`, `oz`, `g`, `kg` |
| `reason` | text | Optional detailed explanation |
| `notes` | text | Optional notes |
| `created_at` | datetime | Record creation timestamp |

### Relationships

References:

- `hydro_season_planting.planting_id`

### Indexes

| Index | Type | Columns |
|---|---|---|
| `PRIMARY` | Primary Key | `waste_id` |
| `fk_hydro_waste_planting` | Foreign Key | `planting_id` |
| `idx_hydro_waste_date` | Index | `wasted_at` |
| `idx_hydro_waste_type` | Index | `waste_type` |

### Business Rules

- Every waste record belongs to one planting assignment.
- Season, position, crop, and variety are derived through the planting assignment.
- Waste records complement harvest records when evaluating production efficiency.

---

## `v_hydro_recent_activity`

**Status:** ✅ Production
**Purpose:** Unified recent activity timeline for operator dashboards and engineering history.
**Source:** MariaDB View

### Source Tables

- `maintenance_log`
- `hydro_tds_reference_reading`

### Used By

- Hydroponics History Browser
- Home Assistant Recent Activity dashboard
- Node-RED history readback
- DBeaver troubleshooting
- Future reporting and dashboard development

### Design Notes

`v_hydro_recent_activity` provides a single chronological readback source for
recent hydroponics activity regardless of where the information is stored.

The view normalizes multiple production tables into a common structure so the
dashboard and History Browser can display fills, doses, EC references, notes,
harvests, and future event types without requiring separate queries.

### Time Handling

For records originating from `maintenance_log`:

- `activity_time` is sourced from `internal_time`.

For records originating from `hydro_tds_reference_reading`:

- `activity_time` is sourced from `captured_at`.

Both values represent local operator time for dashboard display.

### Measurement Display

The view exposes engineering measurement fields appropriate for each event type.

Examples include:

- FILL
  - Water added
  - Dose A
  - Dose B
  - A0 Filtered Before → After
  - A1 Filtered Before → After

- DOSE
  - Dose A and/or Dose B
  - A0 Filtered Before
  - A1 Filtered Before

- EC_REFERENCE
  - Handheld EC
  - A0 Filtered
  - A1 Filtered
  - Tank gallons
  - Water temperature

The view intentionally exposes filtered voltages for operator display while raw
analog measurements remain available in the underlying production tables for
engineering analysis.

---

# Views

Views provide simplified readback for dashboards, reporting, and troubleshooting.

Views are not source data. Permanent records belong in the underlying base
tables.

## Operator History

### `v_hydro_recent_activity`

**Status:** ✅ Production  
**Purpose:** Provides the unified chronological activity feed used by the
Hydro-History dashboard.

The view combines supported operational records into one operator-facing
timeline. Applications should use this view whenever a chronological history
display is required rather than querying the underlying source tables
individually.

**Primary Consumers:**

- Home Assistant Hydro-History dashboard
- Node-RED history refresh workflow
- Operator troubleshooting and event review

**Important Rule:**

`v_hydro_recent_activity` is the authoritative readback interface for the
operator activity timeline. The underlying base tables remain the authoritative
source records.

---

## Inventory and Purchasing Views

| View | Status | Purpose |
|---|---|---|
| `v_inventory_current` | 🚧 Partial | Calculates the current quantity of each dry ingredient from inventory ledger activity. |
| `v_inventory_low` | 🚧 Partial | Identifies ingredients below their configured inventory threshold. |
| `v_inventory_ledger_detail` | 🚧 Partial | Provides inventory ledger entries with ingredient names and related detail. |
| `v_ingredient_inventory` | 🚧 Partial | Provides an ingredient-level inventory summary. |
| `v_remaining_batch_capacity` | 🚧 Partial | Estimates the number of nutrient batches that can be produced from current inventory. |
| `v_purchase_costs_ytd` | 🚧 Partial | Summarizes purchase costs for the current year. |
| `v_unit_cost_per_item_ytd` | 🚧 Partial | Calculates year-to-date unit costs from purchase records. |

---

## Nutrient Batch Views

| View | Status | Purpose |
|---|---|---|
| `v_batch_recipe` | 🚧 Partial | Provides the ingredient recipe for each nutrient batch. |
| `v_nutrient_batches_detail` | 🚧 Partial | Provides detailed nutrient batch records with ingredient information. |

---

## Production Reporting Views

| View | Status | Purpose |
|---|---|---|
| `v_harvests` | ⏳ Planned | Provides harvest records with derived season, position, crop, and variety information. |
| `v_harvest_summary_ytd` | ⏳ Planned | Summarizes current-year harvest production by crop and variety. |

The production views must be rebuilt against the normalized relationship:

```text
hydro_crop
    → crop_variety
        → hydro_season_planting
            → hydro_harvest
```

# Workflow Ownership Map

This section identifies the subsystem responsible for initiating and processing
each database-writing workflow.

The database is the permanent system of record. Home Assistant provides the
operator interface, ESPHome performs physical equipment control, and Node-RED
owns workflow validation, database writes, history refresh, and completion
notifications unless otherwise documented.

| Workflow | Initiated By | Processing Owner | Database Objects | Status |
|---|---|---|---|---|
| Fill / Dose Cycle Logging | ESPHome equipment state changes | Node-RED `Hydroponics_Cycle_Manager.json` | `maintenance_log` | ✅ Production |
| EC / TDS Reference Measurement | Home Assistant Measure EC form | Node-RED `TDS_Reference.json` | `hydro_tds_reference_reading` | ✅ Production |
| Equipment Event Entry | Home Assistant dashboard | Node-RED | `maintenance_log` | ⏳ Planned |
| Dry Ingredient Purchase | Home Assistant dashboard | Node-RED | `purchases`, `purchase_items`, `inventory_ledger` | ⏳ Planned |
| Inventory Adjustment | Home Assistant dashboard | Node-RED | `inventory_ledger` | ⏳ Planned |
| Nutrient Batch Building | Home Assistant dashboard | Node-RED | `nutrient_batches`, `nutrient_batch_items`, `inventory_ledger`, `nutrient_stock_solution` | ⏳ Planned |
| Stock Solution Top-Off | Home Assistant dashboard | Node-RED | `nutrient_stock_solution` | ⏳ Planned |
| Crop Management | Home Assistant dashboard | Node-RED | `hydro_crop`, `crop_variety` | ⏳ Planned |
| Season Setup | Home Assistant dashboard | Node-RED | `hydro_season` | ⏳ Planned |
| Planting Assignment | Home Assistant dashboard | Node-RED | `hydro_season_planting` | ⏳ Planned |
| Harvest Entry | Home Assistant dashboard | Node-RED | `hydro_harvest` | ⏳ Planned |
| Waste Entry | Home Assistant dashboard | Node-RED | `hydro_waste` | ⏳ Planned | | ⏳ Planned |

---

# Current Development Priorities

The database schema is largely complete.

Future development should focus on implementing operator workflows rather than adding new tables.

Current priorities are:

1. History Dashboard
2. Equipment Event Entry
3. Dry Ingredient Purchase Workflow
4. Nutrient Batch Building
5. Stock Solution Inventory Management
6. Inventory Adjustment Workflow
7. Season Setup
8. Planting Assignment
9. Harvest Entry
10. Waste Entry

---

# Revision History

| Date | Revision | Description |
|---|---|---|
| 2026-07-22 | 0.4 | Refactored the engineering measurement model to support dual analog probe channels (A0/A1). Updated `maintenance_log`, `hydro_tds_reference_reading`, and `v_hydro_recent_activity` documentation to replace legacy single-probe terminology with raw and filtered voltage measurements. Expanded view documentation, clarified engineering data ownership, and documented the production readback architecture. |
| 2026-07-01 | 0.3 | Added `water_temp_f` and `operator_note` to `hydro_tds_reference_reading`. Updated Hydro-History design to support annotations on EC reference records and unified history browsing across multiple activity sources. |
| 2026-07-01 | 0.3 | Added Hydro-History browser support, documented operator notes, clarified the project timestamp standard, updated `v_hydro_recent_activity` to use local event time for dashboard readback, and corrected timestamp documentation for production workflows. |
| 2026-06-28 | 0.2 | Reorganized the document into a database reference. Added object inventory, table documentation, views, workflow ownership, and development priorities. Updated to reflect `maintenance_log` as the production event table after retirement of `hydroponics_outside_events`. |

---

## Navigation

**Previous:** [00 – System Overview](00-system-overview.md)

**Next:** [02 – Season & Layout](02-season-and-layout.md)

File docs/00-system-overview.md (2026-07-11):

# Hydroponics Veggie Garden System Overview

**Revision:** 1.0
**Last Updated:** 2026-06-28
**Project Status:** Active Development

---

# Purpose

The Hydroponics Veggie Garden project is an outdoor hydroponic vegetable production system designed to automate nutrient management while collecting long-term operational and crop production data.

The project began as a simple water level monitor using a Wemos D1 Mini and has evolved into a complete monitoring, automation, and data collection platform consisting of:

* ESPHome firmware
* Home Assistant
* Node-RED
* MariaDB
* KiCad hardware design
* Engineering documentation

The long-term objective is to reduce manual maintenance while improving crop production through measurement, automation, and historical analysis.

---

# System Objectives

The system is designed to:

* Monitor reservoir volume
* Automatically refill the nutrient tank
* Maintain nutrient concentration (EC)
* Monitor system flow rates
* Record maintenance and operational events
* Track nutrient inventory
* Track seasonal crop layouts
* Record harvests and waste
* Calculate production costs
* Analyze long-term system performance

Rather than simply automating pumps, the project is intended to become a complete hydroponic crop management system.

---

# Major Components

## ESPHome Controller

The ESP32 controller performs the real-time monitoring and control functions.

Major functions include:

* Reservoir volume measurement (HX711 load cells)
* Water temperature monitoring
* Flow monitoring
* Pump control
* Solenoid valve control
* EC/TDS probe monitoring
* Local safety logic
* Communication with Home Assistant

The controller is intentionally responsible only for low-level hardware control.

---

## Home Assistant

Home Assistant provides the operational user interface.

Responsibilities include:

* Dashboard presentation
* User configuration
* Manual controls
* Notifications
* Helper entities
* Automation coordination
* Device status

The dashboard is designed for day-to-day operation rather than engineering diagnostics.

---

## Node-RED

Node-RED performs higher-level automation and data processing.

Current responsibilities include:

* Nutrient dosing logic
* Event logging
* EC reference capture
* Database writes
* Inventory calculations
* Batch management

As the project grows, Node-RED will become the primary workflow engine.

---

## MariaDB

MariaDB serves as the permanent historical record for the system.

The database stores:

* Fill events
* Dosing events
* EC reference measurements
* Nutrient inventory
* Stock solution batches
* Seasonal planting information
* Harvest data
* Waste tracking
* Operational history

The database allows long-term analysis that cannot be performed using Home Assistant history alone.

---

# Project Organization

The repository is organized into several major components.

| Folder | Purpose |
| --- | --- |
| docs | Engineering documentation |
| esphome | ESPHome firmware |
| home-assistant | Home Assistant packages |
| node-red | Automation flows |
| sql | Database schema and supporting SQL |
| hardware | BOM and enclosure documentation |
| schematic | KiCad schematic and PCB files |

---

# Engineering Philosophy

The project is designed around a layered architecture.

```
Hardware
        │
        ▼
ESPHome
        │
        ▼
Home Assistant
        │
        ▼
Node-RED
        │
        ▼
MariaDB
        │
        ▼
Analysis & Reporting
```

Each layer has a clearly defined responsibility.

Keeping responsibilities separated makes the system easier to maintain and expand.

## Home Assistant Package Organization

Home Assistant packages are organized by **functional responsibility** rather than by entity type.

Each package owns a specific portion of the hydroponic system and should contain
the helpers, template entities, sensors, automations, and supporting logic
required for that responsibility.

### patio_system_constants.yaml

Owns the physical characteristics and operating parameters of the patio
hydroponic system.

Examples include:

- Tank capacity and operating limits
- HX711 calibration
- Flow calibration
- Pump calibration
- Auto-fill operating parameters
- System-specific constants

These values describe the physical system and may differ for each hydroponic
installation.

### patio_dosing_controls.yaml

Owns the routine nutrient maintenance strategy.

Examples include:

- Maintenance dose thresholds
- Target and hard-stop voltages
- Maximum maintenance step size
- Inventory lockout limits
- Maintenance timing
- Maximum maintenance cycles
- Automatic nutrient dosing logic

Separating system constants from dosing control allows future hydroponic
controllers, such as a basement system, to maintain independent hardware
configuration while reusing the same nutrient management architecture.

---

# Future Development

Current development is focused on expanding the system from automation into production management.

Major planned capabilities include:

* Seasonal crop management
* Plant position tracking
* Harvest recording
* Waste recording
* Production cost analysis
* Yield by variety
* Yield by channel position
* Nutrient consumption analysis
* Predictive inventory management
* Dashboard history and reporting

The long-term goal is to understand not only **how** the hydroponic system operates, but **why** certain growing conditions produce better results.

---

# Related Documentation

This document provides the overall project overview.

Additional documentation describes specific portions of the system.

| Document | Description |
|---|---|
| [01 – Database Design](01-database-design.md) | Database schema, normalization, and engineering philosophy. |
| [02 – Season & Layout](02-season-and-layout.md) | Seasonal crop layouts and planting locations. |
| [03 – Harvest & Waste Tracking](03-harvest-and-waste-tracking.md) | Harvest recording, waste tracking, and production analysis. |
| [04 – Dashboard & History Design](04-dashboard-history-design.md) | Dashboard philosophy, Hydro-History, and operator workflows. |
| 05 – Nutrient Management & EC Control *(In Development)* | Automatic nutrient management, EC control strategy, and dosing workflows. |
| 06 – Monitoring & Notification System *(Planned)* | System monitoring, alarms, and notification strategy. |
| 07 – Nutrient Inventory Management *(Planned)* | Dry inventory, stock solution inventory, and batch management. |
| [ESP32 Controller](hardware/esp_32_controller_readme.md) | ESP32 controller hardware and firmware overview. |
| [HX711 Calibration](hardware/calibration-process-hx711.md) | Tank calibration procedure using Home Assistant interpolation. |
| [Alternate Pressure Sensor](hardware/alternate-pressure-sensor.md) | Alternative tank level sensing using a pressure transducer. |
| [Voltage Divider Reference](hardware/voltage_divider_explained.md) | Analog input protection and voltage divider design. |
| [Nutrient Solution Mixing SOP](sop/hydroponics-nutrient-solution-mixing.md) | Printable procedure for preparing Part A and Part B stock solutions. |

---

# Revision History

| Date | Revision | Description |
| --- | --- | --- |
| 2026-06-28 | 1.0 | Initial system overview documenting the transition from a controller project to a complete hydroponic crop management platform. |

---

## Navigation

**Next:** [01 – Database Design](01-database-design.md)

**Related:**

- [ESP32 Controller](hardware/esp_32_controller_readme.md)
- [HX711 Calibration](hardware/calibration-process-hx711.md)
- [Nutrient Solution Mixing SOP](sop/hydroponics-nutrient-solution-mixing.md)

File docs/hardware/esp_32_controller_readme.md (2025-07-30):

# Hydroponics ESP32 Full Control System

This document describes the full-featured **ESP32-based hydroponics controller** as part of the Hydroponic Veggie Garden project. This version expands upon the D1 Mini monitoring build to add **automated control**, **ADC sensor support**, and **multiple operational modes** for complete system management.

---

## 🚀 Key Features

- **Three control modes** (Manual Fill, Auto Fill, Bypass)
- Dual **flow sensors** to verify flow integrity
- **HX711 load cell** for real-time tank weight monitoring
- **DS18B20** temperature sensor for water temperature
- **Optional pressure sensor** via ADC (3.3V range)
- **TDS/EC sensor support** via ESP32 analog input
- **Relay control** for:
  - Water fill solenoid
  - Nutrient dosing pump A
  - Nutrient dosing pump B
- Home Assistant integration via MQTT or native API

---

## 🧭 Modes of Operation

### 1. Manual Fill
- User-initiated tank refill
- Dosing logic based on measured refill volume
- Manual logging timestamps and quantities

### 2. Auto Fill
- Automatically triggers refill when tank level drops
- Initiates nutrient dosing cycle after fill
- Flow sensors and weight confirm successful execution

### 3. Bypass Mode
- All automated control disabled
- Useful for maintenance or troubleshooting

---

## 📐 Calibration Strategy

This version uses a **Home Assistant template sensor** to convert raw HX711 values into gallons. This method offers:

- **No need to reflash the microcontroller** when calibrating
- **6-point calibration system** stored in Home Assistant inputs
- Emergency backup calibration with a **5-gallon bucket**
- Offset tare value managed by a Home Assistant `input_number`

Template sensors and automation logic are documented in:
[home-assistant/patio-calibration.yaml](https://github.com/Gregovate/hydroponic-veggie-garden/blob/main/home-assistant/patio-calibration.yaml)

See detailed explanation: [docs/calibration-explained.md](https://github.com/Gregovate/hydroponic-veggie-garden/blob/main/docs/calibration-explained.md)

---

## 📎 ESPHome Configuration

The full working configuration for the ESP32 is stored at:
[esphome/hydroponics-patio-esp32.yaml](https://github.com/Gregovate/hydroponic-veggie-garden/blob/main/esphome/hydroponics-patio-esp32.yaml)

This includes:
- ADC logic for pressure and TDS sensors
- Switch and GPIO mapping
- Flow sensor calibration constants
- Dallas sensor address and pinout
- Web server, captive portal, and OTA support

---

## 📷 Image Assets
Visual reference images and wiring diagrams are in the
[docs/images](https://github.com/Gregovate/hydroponic-veggie-garden/tree/main/docs/images) folder.

---

## 📄 License

This project is provided under a custom personal-use license:

> "For non-commercial use only. All rights reserved."
>
> Engineering Innovations, LLC  
> Greg Liebig — https://engrinnovations.com

---

## 📚 Related Documents

- [README.md (D1 Mini version)](https://github.com/Gregovate/hydroponic-veggie-garden/blob/main/README.md)
- [Calibration Explained](https://github.com/Gregovate/hydroponic-veggie-garden/blob/main/docs/calibration-explained.md)
- [ESP32 Configuration YAML](https://github.com/Gregovate/hydroponic-veggie-garden/blob/main/esphome/hydroponics-patio-esp32.yaml)
- [Images and Diagrams](https://github.com/Gregovate/hydroponic-veggie-garden/tree/main/docs/images)

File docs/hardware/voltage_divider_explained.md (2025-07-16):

# Understanding the Voltage Divider

This guide explains how a voltage divider works, specifically in the context of safely reducing a 5V sensor signal to 3.3V (or lower) for an ESP32 or ESP8266 analog input.
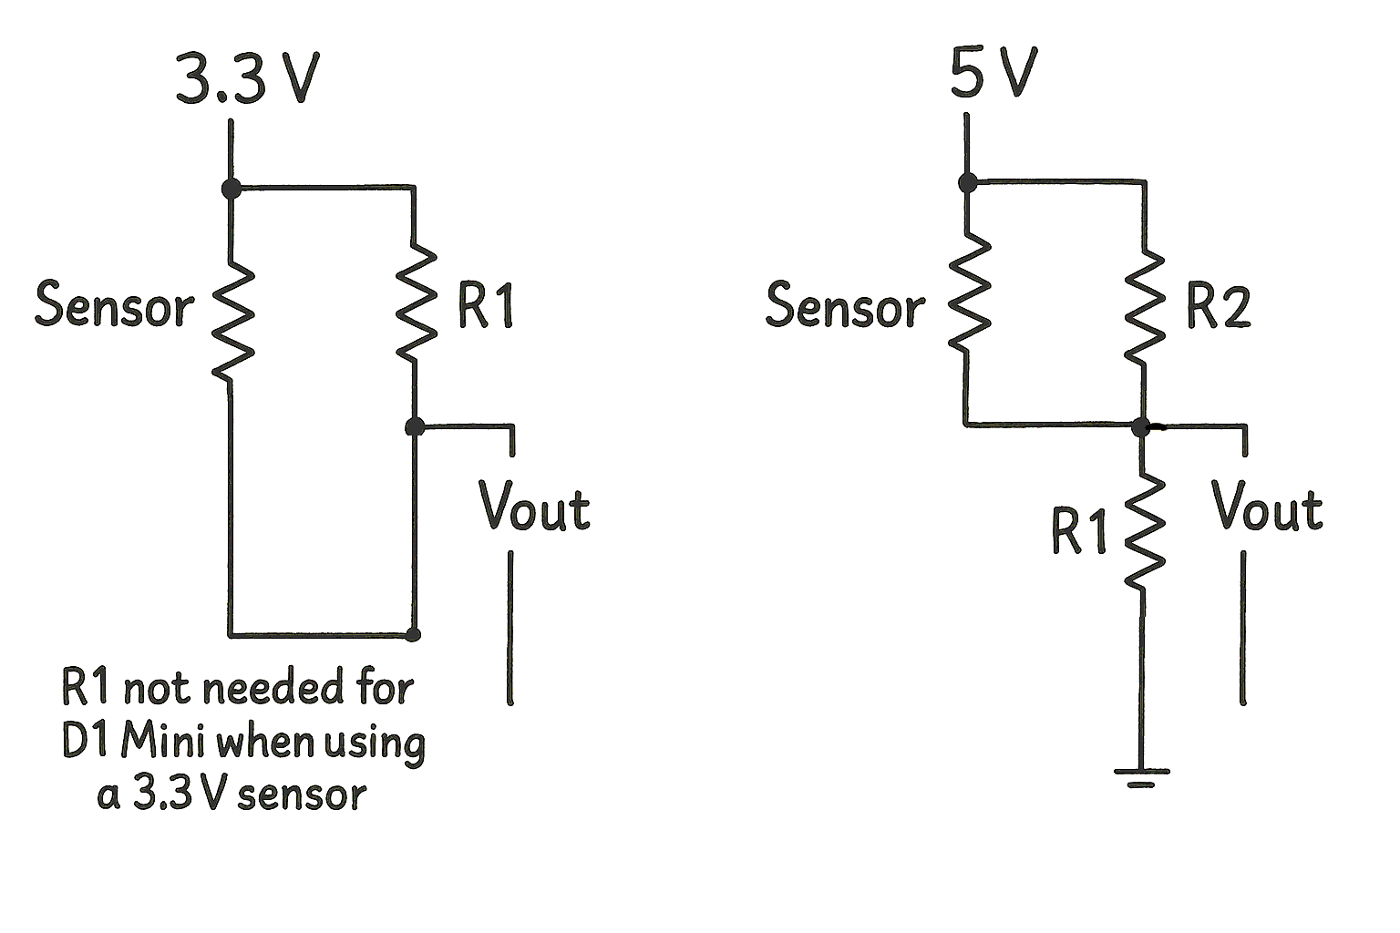
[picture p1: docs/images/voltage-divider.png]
Voltage Divider


---

## Purpose

Some analog sensors output a voltage in the range of 0–5V. However:

- The **ESP32** ADC input only tolerates up to **3.3V**
- The **ESP8266 (D1 Mini)** ADC pin (`A0`) tolerates only **0–1.0V**

Connecting a 5V signal directly to these analog inputs can **permanently damage the microcontroller**. A **voltage divider** solves this by scaling down the voltage using just two resistors.

---

## How It Works

A voltage divider is a simple circuit made from two resistors:

```
      Sensor Output (5V)
         |
        R2
         |
        +----> Vout (to analog input)
         |
        R1
         |
        GND
```

The formula for the output voltage is:

```
Vout = Vin * (R1 / (R1 + R2))
```

Where:

- **Vin** is the sensor voltage (e.g. 5V)
- **R1** is the resistor from the middle point to ground
- **R2** is the resistor from Vin to the middle point

---

## Example: Scaling 5V to \~3.3V

Let’s say the sensor outputs up to **5V**, and we want **Vout ≈ 3.3V**.

Choose:

- **R2 = 10kΩ** (top resistor)
- **R1 = 5.1kΩ** (bottom resistor)

Then:

```
Vout = 5 * (5.1 / (10 + 5.1)) ≈ 3.3V
```

This is perfect for safe use with the ESP32’s ADC.

---

## For ESP8266 (A0 Only Allows 1.0V)

If you're using a D1 Mini (ESP8266), you'll need **further voltage reduction**. Here’s one working pair:

- **R2 = 100kΩ**
- **R1 = 20kΩ**

Result:

```
Vout = 5 * (20 / 120) ≈ 0.83V (safe for A0)
```

---

## Notes

- Use precision resistors (±1% tolerance if available)
- Always connect sensor ground to the ESP ground
- You can use any resistor values as long as their **ratio** gives the correct output
- Keep resistor values reasonably high (to avoid unnecessary power draw)

---

## Summary

- A voltage divider is essential when using 5V analog sensors with 3.3V (or 1.0V) microcontrollers.
- Two resistors scale the signal safely to the desired range.
- The resistor values you choose depend on your target voltage and the microcontroller’s limits.

By wiring your voltage divider as shown above and selecting the correct resistor pair, you can safely read tank level data from a 5V sensor using ESPHome. Just be sure to check your voltages before connecting to your micro controller!

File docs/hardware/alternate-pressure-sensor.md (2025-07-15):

**Using a Submersible Liquid Level Pressure Sensor with ESPHome**

This guide explains how to replace an HX711 load cell system with a submersible hydrostatic pressure sensor (e.g., 1m range, 5m cable) for use with ESPHome on an ESP8266 (D1 Mini) or ESP32 Mini board.

---

## 1. Overview

Submersible liquid level sensors measure pressure at the bottom of a tank and convert it to voltage. This voltage is proportional to the liquid height. These sensors are ideal for large tanks where load cells are impractical.

---

## 2. Typical Sensor Wiring

Most submersible hydrostatic sensors have three wires:

| Wire Color | Function |
| --- | --- |
| Red | VCC (typically 5V) |
| Black | GND |
| Yellow | Analog Signal (0-5V) |

**Note:** Confirm your sensor's wiring and voltage range before connecting.

---

## 3. Using with D1 Mini (ESP8266)

### ⚠ Important:

- The ESP8266 analog pin (A0) only accepts **0–1.0V**.
- Most sensors output **0–5V**, so a voltage divider is required.

### Voltage Divider Example (5V to 1V):

Use two resistors:

- R1 = 20kΩ (connects sensor output to A0)
- R2 = 5kΩ (connects A0 to GND)

This reduces 5V to 1V at full scale:

```
Vout = Vin * (R2 / (R1 + R2)) = 5V * (5k / 25k) = 1V
```

### Wiring Table:

| Sensor Wire | Connects To |
| --- | --- |
| Red | 5V (D1 Mini VCC or external) |
| Black | GND |
| Yellow | Voltage divider → A0 |

---

## 4. Using with Mini ESP32

- The ESP32 supports **true 0–3.3V** analog readings on many ADC pins (e.g., GPIO34, GPIO35).
- No voltage divider is needed if the sensor outputs **≤3.3V**.
- If using a 5V output sensor, **a voltage divider is still required**.

### ESP32 Example Wiring (Sensor outputs 0–3.3V):

| Sensor Wire | Connects To |
| --- | --- |
| Red | 5V or 3.3V (check spec) |
| Black | GND |
| Yellow | GPIO34 |

---

## 5. ESPHome Configuration

### For D1 Mini (A0):

```yaml
sensor:
  - platform: adc
    pin: A0
    name: "Tank Pressure (Raw)"
    update_interval: 10s
    filters:
      - calibrate_linear:
          - 0.10 -> 0    # Voltage at empty
          - 0.90 -> 40   # Voltage at full (in inches, cm, etc.)
    unit_of_measurement: "in"
    id: tank_level_sensor
```

### For ESP32 (GPIO34):

```yaml
sensor:
  - platform: adc
    pin: GPIO34
    name: "Tank Pressure (Raw)"
    update_interval: 10s
    attenuation: 11db  # Enables full 3.3V range
    filters:
      - calibrate_linear:
          - 0.1 -> 0
          - 2.5 -> 40
    unit_of_measurement: "in"
    id: tank_level_sensor
```

### Convert to Gallons (Template Sensor):

```yaml
  - platform: template
    name: "Tank Gallons"
    unit_of_measurement: "gal"
    lambda: |-
      return id(tank_level_sensor).state * 5.1;  // Replace with correct factor
    update_interval: 10s
```

---

## 6. Benefits and Limitations

### Benefits:

- No weight limitation (great for 200+ gallon tanks)
- Simple installation (drop-in sensor)
- Fewer moving parts

### Limitations:

- Requires analog input
- Must calibrate accurately
- Some sensors require 12V (check datasheet)

---

## 7. Summary

| Feature | HX711 Load Cell | Submersible Pressure Sensor  |
| --- | --- | --- |
| Measures | Weight | Water pressure (height) |
| ESP Pin Type | Digital (HX711) | Analog (ADC) |
| Calibration Complexity | Moderate | Easy with `calibrate_linear` |
| Best Use Case | Small tanks, precise | Large tanks (e.g., 200 gal)  |

---

For tanks too large to be measured accurately with a platform scale, this hydrostatic solution offers a clean, scalable, and ESPHome-compatible option.

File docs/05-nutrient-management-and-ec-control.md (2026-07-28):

# Nutrient Management and EC Control

Revision: 0.3
Last Updated: 2026-07-20
Status: Draft

---

# Purpose

This document describes the nutrient management strategy used by the hydroponic vegetable garden.

It documents how nutrient concentration is measured, maintained, validated, and recorded while defining the engineering philosophy behind automatic nutrient dosing, long-term EC control, and controller operation.

This document focuses on **maintaining nutrient concentration within the hydroponic reservoir**.

Preparation of nutrient stock solutions, inventory management, purchasing, batch preparation, and inventory tracking are documented separately in **07 – Nutrient Inventory Management**.

Unlike the nutrient stock solution mixing procedure, this document focuses on **system operation** rather than chemical preparation.

---

# Design Goals

The nutrient management system is intended to:

- Maintain healthy nutrient concentrations.
- Automatically replace nutrients lost during refill events.
- Maintain nutrient concentration during normal circulation.
- Prevent over-dosing.
- Record all nutrient additions.
- Validate sensor performance using independent handheld and installed sensor measurements.
- Compare multiple installed conductivity sensors under identical operating conditions.
- Support long-term calibration and evaluation of installed conductivity sensors.
- Separate raw conductivity measurement from calculated EC estimation.
- Build a historical database for long-term engineering analysis and future controller improvements.
- Preserve lifetime nutrient usage without resetting cumulative dosing totals.
- Provide reliable controller state information for operator awareness.
- Support future improvements to automatic nutrient dosing algorithms.

**Inventory management, nutrient batch preparation, and chemical purchasing are documented separately in
[07 – Nutrient Inventory Management](07-nutrient-inventory-management.md).**

---

# Nutrient Management Philosophy

The nutrient management system is designed to maintain healthy nutrient
concentrations while minimizing operator intervention and preventing
over-dosing.

Unlike traditional hydroponic controllers that rely on calibrated EC probes and
PID control, this system uses a staged engineering approach centered around a
continuously monitored analog conductivity probe, periodic handheld EC
validation, and conservative proportional maintenance dosing.

## Design Objectives

The controller is intended to:

- Maintain stable nutrient concentration during normal operation.
- Automatically replace nutrients added during refill events.
- Gradually restore nutrient concentration during circulation when EC declines.
- Prevent excessive nutrient additions.
- Record every nutrient addition for historical analysis.
- Continuously improve probe calibration using field data.

## Configurable Maintenance Timing

Routine maintenance dosing uses several configurable timing parameters to allow
the controller behavior to be tuned without modifying automation logic.

### Maintenance Debounce

Defines how long the probe voltage must remain below the maintenance threshold
before a maintenance dose cycle is permitted to begin.

This prevents transient voltage changes from initiating unnecessary nutrient
corrections.

### Mixing Time

Defines how long the circulation system is allowed to mix newly added nutrients
before the post-dose TDS measurement is evaluated.

This value may require adjustment if tank volume or circulation flow rates are
changed.

### Next Maintenance Dose Offset

Defines the minimum time that must elapse after completion of the mixing period
before another automatic maintenance dose may begin.

This provides a short stabilization period between consecutive maintenance dose
cycles while allowing the controller to continue correcting nutrient levels if
required.

### Maximum Maintenance Cycles

Defines the maximum number of consecutive automatic maintenance correction
cycles permitted during a single maintenance event.

This prevents repeated nutrient additions caused by abnormal sensor behavior or
unexpected system faults while still allowing gradual correction toward the
target operating range.

## Fill-Based Nutrient Replacement

Whenever water is added to the system, the controller measures the actual gallons
added.

The patio_controller automatically calculates the required Part A and Part B
nutrient additions using the configured nutrient ratio and injects both parts
without operator intervention.

This provides repeatable nutrient replacement after every fill event.

---

# Nutrient Inventory Management

## Design Philosophy

The nutrient management system maintains an estimated inventory of nutrient
solution at two levels:

- Production nutrient containers connected directly to the dosing pumps.
- Backup nutrient containers used to replenish the production containers.

The objective is to maintain sufficient inventory accuracy for normal operation,
batch planning, and chemical purchasing. Laboratory precision is not required.
Small estimation errors are acceptable and may be corrected periodically through
manual inventory adjustment.

## Production Inventory

The controller maintains an estimated inventory for each production nutrient
container.

Production inventory decreases automatically whenever the nutrient dosing pumps
operate.

Production inventory increases only when nutrient is transferred from the
corresponding backup container.

## Backup Inventory

The controller maintains an estimated inventory for each backup nutrient
container.

Backup inventory increases only when a new nutrient batch is prepared.

Backup inventory decreases whenever nutrient is transferred into a production
container.

To preserve recipe consistency, new nutrient batches are prepared only after the
corresponding backup container has been emptied. Existing nutrient is never
mixed with a newly prepared batch.

## Production Refill Workflow

The operator's goal is to refill each production container to its nominal full
capacity of **3780 mL (1 US gallon)** whenever sufficient nutrient exists in the
backup container.

The controller determines:

- Current production inventory.
- Current backup inventory.
- Quantity required to refill the production container.

If sufficient nutrient exists in the backup container, the production container
is refilled to full capacity.

If insufficient nutrient remains, all remaining nutrient is transferred from the
backup container into the production container. The backup inventory then
becomes zero.

The refill workflow automatically updates:

- Production inventory.
- Backup inventory.
- Production refill baseline.
- Maintenance history.

Cumulative nutrient usage is never reset during this process.

## Batch Preparation

Preparing a new nutrient batch replenishes only the corresponding backup
container.

Batch preparation history, formulation information, and cost records remain
independent of operational inventory tracking.

## Manual Inventory Adjustment

Estimated inventory is considered sufficiently accurate for normal operation.

If desired, the operator may periodically correct either production or backup
inventory using container graduations, measured volume, or container weight.

Manual adjustments update the estimated inventory without affecting cumulative
nutrient usage history.

## Maintenance Nutrient Control

During normal circulation, plants continuously consume nutrients while water
volume changes more slowly.

The installed conductivity probe is continuously monitored for changes in raw
probe voltage.

When the measured voltage falls below the configured maintenance threshold, the
controller performs a small maintenance dose.

Rather than using a fixed maintenance dose, the controller uses **proportional
step dosing**.

The requested maintenance dose is scaled according to the difference between:

- Current probe voltage
- Target probe voltage

This provides larger corrections when nutrient concentration is significantly
low while automatically reducing the correction size as the target is
approached.

### Proportional Step Dosing

Maintenance dosing uses a proportional step algorithm rather than a fixed dose.

Three configurable voltage limits define the controller behavior:

- **Low Trigger Voltage** – begins maintenance dosing.
- **Target Voltage** – desired operating voltage after maintenance.
- **Hard Stop Voltage** – prevents additional nutrient additions.

When the measured probe voltage falls below the Low Trigger Voltage, the
controller calculates a maintenance dose proportional to the voltage error:

```
Voltage Error = Target Voltage − Current Voltage
```

The requested maintenance dose is then calculated as:

```
Requested Dose =
Tank Gallons × Maximum Step mL/Gallon × Correction Ratio
```

where the Correction Ratio is limited between 0 and 1.

As the measured voltage approaches the Target Voltage, the requested dose
becomes progressively smaller.

This proportional approach provides smooth correction while reducing the
likelihood of overshoot without requiring the complexity of a PID controller.

## Safety Philosophy

Several independent limits prevent excessive nutrient additions.

Maintenance dosing is permitted only when:

- Outside Controller Mode is Auto Fill - Auto Dose.
- The circulation system is operating normally.
- Inventory is above the configured reserve level.
- Tank volume is valid.
- Fill and manual dosing are not active.
- Probe voltage remains below the maintenance target.
- Probe voltage is below the configured hard-stop limit.

Maintenance dosing immediately stops when any safety condition is violated.

Maintenance dosing is additionally limited by a configurable maximum number of
successive correction cycles to prevent repeated dosing caused by abnormal
sensor behavior or unexpected system faults.

## Continuous Monitoring

The installed conductivity sensors are used as **process measurement sensors**, not laboratory instruments.

Their purpose is to detect relative changes in nutrient concentration during normal system operation while providing continuous measurements that can be compared against periodic handheld EC reference readings.

The current measurement architecture consists of:

- **KEYESTUDIO Analog TDS Sensor** — The production process measurement sensor used by the automatic maintenance dosing system.
- **DFRobot Gravity Analog TDS Sensor** — An independent validation sensor operated in parallel with the production sensor for long-term performance evaluation.
- **Bluelab Truncheon EC Meter** — The production reference instrument used for periodic verification of the installed sensors.
- **Estimated EC** — A calculated engineering estimate generated by Home Assistant from the measured sensor voltage. This is a derived value rather than a direct measurement.

Each measurement source serves a different purpose and should not be considered interchangeable.

Because conductivity measurements may be influenced by temperature, probe placement, water circulation, fouling, aging, electronics, and other environmental factors, the system does not rely on a single sensor or calculated EC value.

Instead, long-term confidence is established by comparing multiple measurement sources under identical operating conditions and preserving those measurements for historical analysis while the system is under development.

## Long-Term Calibration Strategy

The production reference remains the handheld EC meter.

Periodic reference measurements record:

- KEYESTUDIO analog sensor voltage
- DFRobot analog sensor voltage
- Handheld EC measurement
- Estimated Tank EC
- Water temperature
- Tank volume
- Rainfall and estimated dilution
- Environmental conditions
- Operator notes

These synchronized measurements are stored in the historical database and used to:

- Compare the performance of both installed analog sensors.
- Identify sensor drift, fouling, or installation effects.
- Evaluate the accuracy of the Estimated Tank EC calculation.
- Improve the voltage-to-EC estimation model over time.
- Build confidence in long-term unattended controller operation.

Estimated Tank EC is therefore considered an engineering estimate rather than a primary control variable until sufficient historical validation data has been collected.

---

## Handheld Engineering Reference

A Bluelab Truncheon EC meter is used as the engineering reference instrument
during calibration and validation.

No measurement system is perfect.

The handheld EC meter serves as the engineering reference standard during
calibration, while the permanently installed analog probes provide continuous
process measurements between handheld reference readings.

Comparing the two measurement systems improves confidence in nutrient control,
helps identify sensor drift, and supports ongoing refinement of the EC
estimation model.

The Truncheon displays EC using illuminated LEDs at **0.2 EC increments**
rather than a continuous numeric display. To preserve additional engineering
resolution, reference measurements are recorded using the following convention:

- **Even-tenth values** (1.8, 2.0, 2.2, etc.) indicate the Truncheon displayed a
  stable EC value.

- **Odd-tenth values** (1.9, 2.1, 2.3, etc.) indicate the Truncheon was
  alternating between the adjacent even EC values and the midpoint was recorded
  by the operator.

This convention preserves additional information without requiring a
higher-resolution laboratory instrument and provides a consistent engineering
reference for calibration and long-term sensor evaluation.

The handheld meter is used periodically to validate the permanently installed
analog probes. Between handheld reference measurements, the fixed analog probes
continuously monitor changes in nutrient concentration resulting from plant
uptake, evaporation, rainfall, nutrient additions, and water additions.

## Fixed Analog Process Sensors

The outdoor hydroponics controller continuously monitors nutrient solution using
two permanently installed analog conductivity sensors operating in parallel.

Current channel assignments are:

| Channel | Sensor |
|---|---|
| **A0** | KEYESTUDIO analog conductivity sensor |
| **A1** | DFRobot Gravity analog conductivity sensor |

Both sensors continuously measure changes in nutrient concentration under
identical operating conditions. Operating two independent measurement channels
allows long-term comparison of sensor behavior while minimizing the influence of
changing reservoir conditions.

The dual-sensor architecture is used to:

- Compare long-term stability.
- Detect sensor drift.
- Evaluate sensor repeatability.
- Compare response to dilution and nutrient additions.
- Support development and validation of future EC estimation models.

At present, the automatic maintenance dosing algorithm uses the production
measurement channel while the second channel continues to accumulate engineering
data for long-term evaluation.

Both channels are recorded with every handheld EC reference measurement to
provide synchronized calibration data for ongoing model development.

## Estimated Tank EC

Estimated Tank EC is calculated by Home Assistant using the measured analog sensor voltage and the current engineering estimation model.

Estimated Tank EC is intended to provide a convenient operator-facing value for monitoring system performance.

Because the estimation model will continue to evolve as additional validation data is collected, Estimated Tank EC is considered an engineering estimate rather than a laboratory measurement.

## Supporting Measurements

Additional operating conditions are recorded whenever practical to improve interpretation of conductivity measurements.

These include:

- Water temperature
- Tank volume
- Rainfall since the previous reference measurement
- Estimated rainwater dilution
- Operator observations

Together, these measurements provide the engineering context needed to evaluate long-term sensor performance and improve future EC estimation models.
---

# Probe Voltage vs. EC

Neither installed analog sensor measures electrical conductivity (EC) directly. Instead, each sensor produces an analog output voltage that varies with the conductivity of the solution.

The relationship between sensor voltage and actual EC is influenced by multiple factors and should not be assumed to be constant under all operating conditions.

Engineering observations have shown that analog sensor voltage may be affected by:

- Nutrient concentration
- Water temperature
- Probe location within the reservoir
- Water circulation and local mixing
- Tank volume
- Rainfall and dilution
- Probe fouling or aging
- Sensor-to-sensor variation
- Electronic component tolerances

Because of these influences, raw sensor voltage should be treated as a process measurement rather than a calibrated EC value.

The installed analog sensors are intended to detect relative changes in nutrient concentration during normal operation. Absolute nutrient concentration is verified through periodic handheld EC reference measurements.

The long-term objective is to develop an engineering estimation model that provides a useful approximation of tank EC while preserving the original raw sensor measurements for future analysis and model refinement.

Until sufficient validation data has been collected, automatic maintenance dosing will continue to be based on the proven production sensor, while additional sensors and estimation models are evaluated in parallel.

### Future Validation

Current engineering observations indicate that analog sensor voltage is influenced by more than nutrient concentration alone.

Ongoing investigation includes:

- Sensor installation location within the reservoir.
- Water circulation and local mixing effects.
- Tank volume.
- Water temperature.
- Probe fouling and long-term aging.
- Rainfall and dilution effects.
- Sensor-to-sensor repeatability.
- Long-term stability of the KEYESTUDIO and DFRobot analog sensors.
- Accuracy of the Estimated Tank EC calculation.

Additional validation is planned to determine the most suitable long-term measurement strategy for unattended controller operation.

The analog sensor interface boards are currently powered from the 5 V supply while the ADS1115 analog-to-digital converter operates from the 3.3 V supply.

Future increases in target EC during heavy fruit production should include validation of the maximum analog output voltage produced by each analog sensor interface to ensure the signals remain within the safe operating range of the ADS1115 while providing adequate measurement resolution.

These validation activities should be completed before modifying the production automatic maintenance dosing strategy or implementing a final voltage-to-EC estimation model.

---

# Handheld EC Reference Measurements

The handheld EC reference workflow provides the production reference measurement for evaluating the installed analog conductivity sensors.

Reference measurements are initiated from the Home Assistant **Measure EC** workflow after the reservoir has reached a stable operating condition.

Each reference measurement records:

- KEYESTUDIO analog sensor voltage
- DFRobot analog sensor voltage (during the current validation phase)
- Handheld EC measurement
- Estimated Tank EC
- Water temperature
- Tank volume
- Rainfall and estimated dilution
- Environmental conditions
- Operator notes

These measurements are captured as a synchronized snapshot and stored in the historical database.

Handheld reference measurements are typically performed:

- During routine system inspections.
- After significant water additions.
- After nutrient adjustments.
- During sensor validation and troubleshooting.
- Whenever abnormal controller behavior is observed.

The historical reference data is used to:

- Compare the performance of the installed analog sensors.
- Identify long-term sensor drift or fouling.
- Evaluate the accuracy of the Estimated Tank EC calculation.
- Improve the voltage-to-EC estimation model.
- Verify that the automatic maintenance dosing system continues to operate as expected.

Because all measurements are recorded at the same point in time, the historical database provides an engineering record that supports both routine operation and future refinement of the nutrient management system.

---

## Controller Operating Modes

The outside hydroponics controller supports three operating modes. Each mode
defines who is responsible for controlling water and nutrient addition.

### 🤖 Auto Fill - Auto Dose

**Purpose**

Fully automatic operation.

**Operator Responsibilities**

- Configure the Auto Fill Threshold.
- Configure the Tank Full Target.

**Controller Responsibilities**

- Detect low tank level.
- Wait for the debounce period.
- Schedule the automatic fill.
- Fill the tank to the configured target.
- Calculate nutrient requirements based on water added.
- Automatically dose Parts A and B.
- Record the completed cycle.
- Generate notifications.

---

### 🧪 Manual Fill - Auto Dose

**Purpose**

Semi-automatic operation.

The operator decides how much water to add. The controller automatically
calculates and injects the required nutrients.

**Operator Responsibilities**

- Specify the desired fill amount.
- Start the fill.

**Controller Responsibilities**

- Measure water added.
- Calculate nutrient requirements.
- Automatically dose Parts A and B.
- Record the completed cycle.
- Generate notifications.

---

### 🟥 ESP-Override

**Purpose**

Manual service and maintenance mode.

Automation is intentionally bypassed. The controller functions only as a
hardware interface while providing operator decision support.

**Operator Responsibilities**

- Specify the desired fill amount, if applicable.
- Review the recommended nutrient dose calculated by the **🧮 ESP-Override Dose Recommendation Calculator** automation.
- Decide whether to use the recommended dose or a different amount.
- Start and stop fills.
- Manually dose Part A.
- Manually dose Part B.
- Determine all quantities and timing.

**System Responsibilities**

- The **🧮 ESP-Override Dose Recommendation Calculator** automation calculates and displays a recommended nutrient dose based on the specified fill amount.
- The patio_controller operates pumps and valves only when commanded by the operator.
- The patio_controller records manual execution events when appropriate.

---

### Summary

| Mode | Water Control | Nutrient Control | Typical Use |
|---|---|---|---|
| **Auto Fill - Auto Dose** | Automatic | Automatic | Normal operation |
| **Manual Fill - Auto Dose** | Manual | Automatic | Partial refills |
| **ESP-Override** | Manual | Manual | Service, testing, calibration |

---

# EC Reference Data Collection

Each handheld EC reference measurement is permanently stored in the historical database as an engineering reference record.

The database is intended to preserve both the measured values and the operating conditions under which they were obtained, allowing historical analysis long after the individual measurements were taken.

Typical recorded information includes:

- Date and time
- KEYESTUDIO analog sensor voltage
- DFRobot analog sensor voltage (during validation)
- Handheld EC measurement
- Estimated Tank EC
- Water temperature
- Tank volume
- Rainfall and estimated dilution
- Environmental conditions
- Operator notes

Collecting complete operating context allows historical measurements to be interpreted correctly and compared under similar operating conditions.

The historical database supports:

- Long-term evaluation of installed sensor performance.
- Identification of sensor drift and fouling.
- Comparison of multiple analog sensor technologies.
- Validation of the Estimated Tank EC calculation.
- Refinement of future voltage-to-EC estimation models.
- Engineering analysis of nutrient management performance over multiple growing seasons.

The historical database is intended to serve as the permanent engineering record for development, validation, and continuous improvement of the outdoor hydroponics nutrient management system.

---

# Dashboard Integration

The Home Assistant dashboard provides the primary operator interface for the outdoor hydroponics controller.

Rather than serving as a simple collection of sensor values, the dashboard presents the current operating state of the nutrient management system and provides access to both manual and automatic controller functions.

Current dashboard features include:

- Live analog sensor voltage
- Estimated Tank EC
- Tank volume
- Water temperature
- Flow rates
- Current controller operating mode
- Automatic maintenance dosing status
- Maintenance dose recommendations
- Fill status and progress
- Last handheld EC reference measurement
- Recent maintenance activity and event history
- Nutrient inventory and cumulative dosing totals
- Rainfall and environmental monitoring

The dashboard also provides operator controls for:

- Automatic maintenance dosing.
- Manual nutrient dosing.
- Manual water fill operations.
- ESP-Override maintenance functions.
- Recording handheld EC reference measurements.
- Entering engineering field notes.

Dashboard information is derived from live ESPHome measurements, Home Assistant calculations, Node-RED workflow status, and historical database records to present a unified view of current system operation.

The dashboard continues to evolve as additional controller capabilities are implemented, with the objective of providing a complete operator interface without requiring direct access to ESPHome logs, Home Assistant traces, Node-RED flows, or database queries.

---

# Navigation

**Previous**

- [04 – Dashboard & History Design](04-dashboard-history-design.md)

**Next**

- [06 – Monitoring & Notification System](06-monitoring-and-notification-system.md)

**Related Documentation**

- [00 – System Overview](00-system-overview.md)
- [01 – Database Design](01-database-design.md)
- [Nutrient Solution Mixing SOP](sop/hydroponics-nutrient-solution-mixing.md)

---

# Revision History

| Date | Revision | Description |
|---|---|---|
| 2026-07-20 | 0.3 | Expanded measurement architecture, EC estimation strategy, sensor validation methodology, handheld reference workflow, dashboard integration, and engineering documentation. |
| 2026-07-06 | 0.2 | Added nutrient management philosophy, operating modes, and maintenance dosing strategy. |
| 2026-07-01 | 0.1 | Initial document outline. |

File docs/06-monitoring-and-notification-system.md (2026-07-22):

# Monitoring and Notification System

**Revision:** 0.2  
**Last Updated:** 2026-07-20  
**Status:** Draft

---

# Purpose

This document describes how the outdoor hydroponic system monitors its operating condition, detects abnormal behavior, records significant operational events, and notifies the operator when intervention may be required.

The monitoring system is intended to detect equipment failures, sensor faults, abnormal operating conditions, communication failures, and inventory shortages before they negatively impact plant health or system reliability.

This document also defines the monitoring architecture, notification strategy, event logging philosophy, and the responsibilities of the various software components that together provide operational awareness of the hydroponic system.

---

# Design Goals

The monitoring and notification system is intended to:

- Detect equipment failures.
- Detect abnormal operating conditions.
- Detect communication failures between system components.
- Prevent crop loss through early fault detection.
- Verify that automated controller operations complete as expected.
- Notify the operator only when action is required.
- Minimize nuisance alarms and notification fatigue.
- Record significant operational events and engineering observations.
- Support long-term reliability analysis and troubleshooting.
- Provide clear operator awareness of current system status.

---
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

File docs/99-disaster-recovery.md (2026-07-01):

# Disaster Recovery

**Revision:** 0.1  
**Last Updated:** 2026-07-01  
**Status:** Outline

---

# Purpose

This document describes the procedures required to recover the hydroponic system following a major hardware, software, or data loss event.

The objective is to restore the complete system with minimal downtime while preserving historical data and configuration whenever possible.

This document assumes the engineering documentation, source code, and repository remain available.

---
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

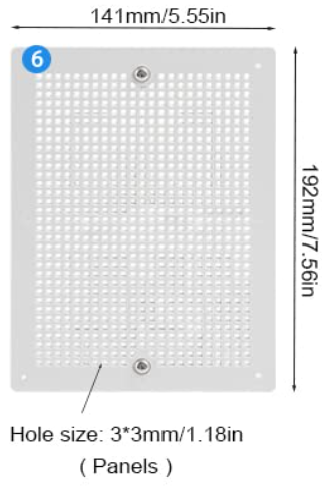
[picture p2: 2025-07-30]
hardware/images/panel.png

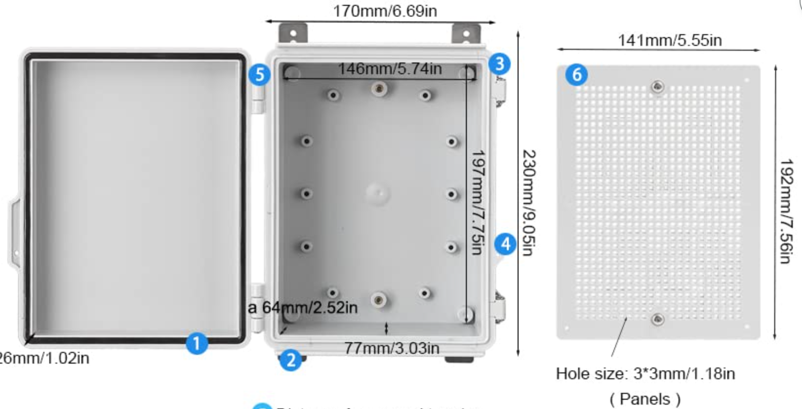
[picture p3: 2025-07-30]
hardware/images/project-box-8.7x6.7x4.4.png

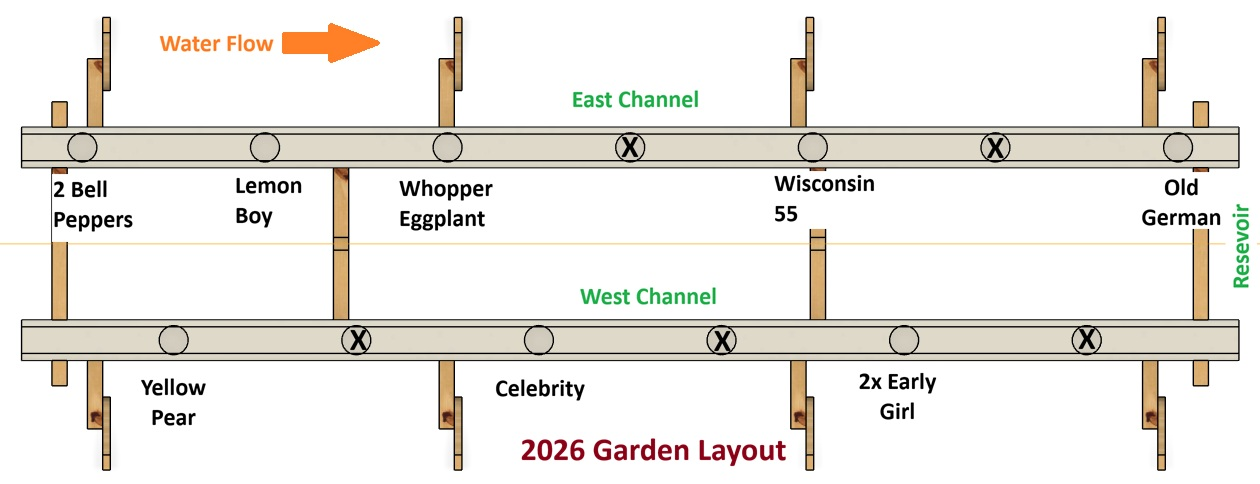
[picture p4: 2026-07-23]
docs/images/2026_Garden_Layout.png

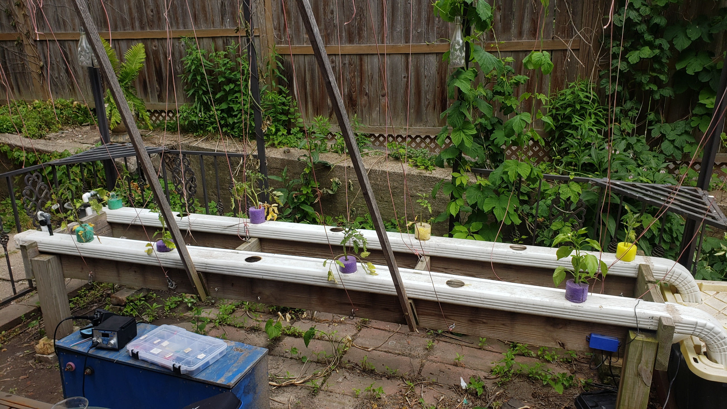
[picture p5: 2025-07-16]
docs/images/garden-2025-06-16.jpg

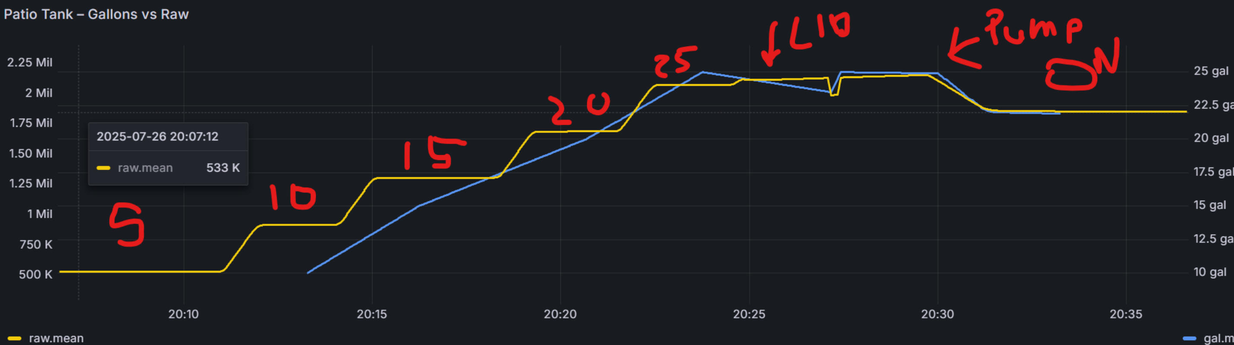
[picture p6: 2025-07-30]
docs/images/new-fill-profile.png

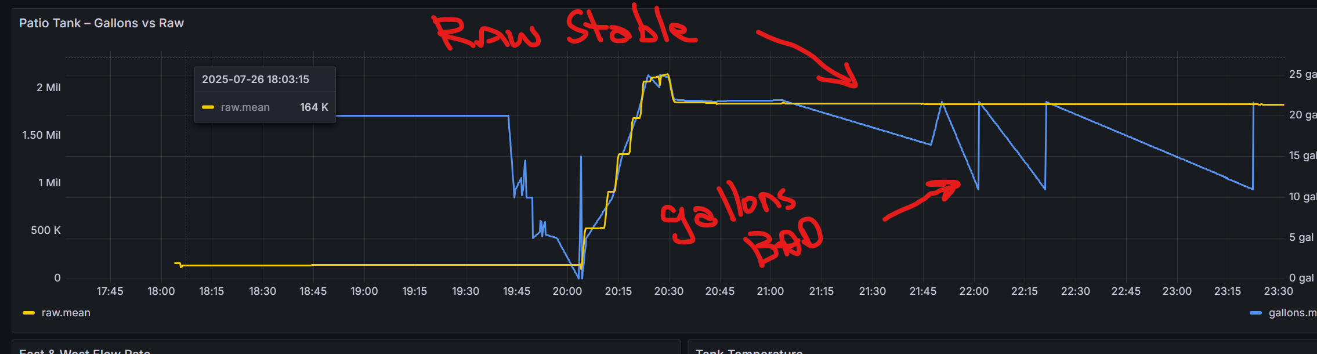
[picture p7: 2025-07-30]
docs/images/rebuilt-scale.png

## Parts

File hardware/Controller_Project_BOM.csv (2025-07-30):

Qty | Item | Purchase Link
1 | ESP-WROOM-32 ESP32 Development Board | https://www.amazon.com/dp/B0B82BBKCY?ref=fed_asin_title&th=1
1 | ESP32-DevKitC-32 Expansion Board for Arduino | https://www.amazon.com/dp/B0B82BBKCY?ref=fed_asin_title&th=1
1 | HiLetgo ADS1115 16-Bit 4-Channel I2C ADC (3-pack) | https://www.amazon.com/dp/B07VPFLSMX?ref=fed_asin_title
1 | KEYESTUDIO TDS Meter Probe Water Quality Sensor | https://www.amazon.com/dp/B08DGLY3J2?ref=fed_asin_title
1 | DC 12V Relay Module 4 Channel with Optocoupler | https://www.amazon.com/dp/B098DXRTT8?ref=fed_asin_title&th=1
1 | Submersible Liquid Level Sensor, 1m Range, 5m Cable | https://www.amazon.com/dp/B0CSWFWCVK?ref=fed_asin_title&th=1
2 | Peristaltic Dosing Pump 12V with 4 Connectors | https://www.amazon.com/dp/B0DC9TF1BS?ref=fed_asin_title&th=1
1 | Gikfun DS18B20 Waterproof Temperature Sensor (5-pack) | https://www.amazon.com/Gikfun-DS18B20-Temperature-Waterproof-EK1083x3/dp/B012C597T0
1 | Beduan Brass Electric Solenoid Valve 1/2" 12V | https://www.amazon.com/dp/B07N6246YB?ref=fed_asin_title&th=1
1 | 4PCS 50KG Load Cell with HX711 Module | https://www.amazon.com/dp/B0CWLHXHMD?ref=fed_asin_title
2 | 1N5819 Schottky Diode 1A 40V | https://www.amazon.com/dp/B0CKSHSWPS?ref=fed_asin_title
2 | IRLZ44N MOSFET 47A 55V Logic Level TO-220 | https://www.amazon.com/dp/B0CBKH4XGL?ref=fed_asin_title

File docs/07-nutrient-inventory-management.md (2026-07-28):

# Nutrient Inventory Management

**Revision:** 0.1  
**Last Updated:** 2026-07-01  
**Status:** Outline

---

# Purpose

This document describes how raw nutrients, prepared nutrient stock solutions, and nutrient batches are managed throughout the hydroponic system.

The objective is to maintain sufficient nutrient inventory for uninterrupted operation while providing complete traceability of nutrient purchases, batch preparation, inventory movement, consumption, and operating costs.

This document defines the nutrient inventory architecture, including the management of raw chemical inventory, prepared backup stock, production nutrient containers, and the inventory workflows that connect them.

Preparation of nutrient stock solutions is documented separately in the **Nutrient Solution Mixing SOP**. Automatic nutrient dosing and reservoir EC control are documented in **05 – Nutrient Management and EC Control**.

---

# Design Goals

The nutrient inventory system is intended to:

- Maintain sufficient nutrient inventory for uninterrupted hydroponic operation.
- Track raw chemical inventory.
- Track prepared backup nutrient inventory.
- Track production nutrient container inventory.
- Record nutrient purchases.
- Record nutrient batch preparation.
- Record nutrient transfers from backup inventory to production containers.
- Automatically account for nutrient consumption through controller dosing.
- Maintain complete traceability from raw chemical purchase through nutrient consumption.
- Support nutrient batch traceability and cost analysis.
- Predict future inventory requirements and remaining batch capacity.
- Provide proactive notifications when additional nutrient batches or chemical purchases are required.
- Support long-term engineering analysis of nutrient usage, inventory, and operating costs.

---

# Inventory Philosophy

The nutrient inventory system is based on the principle that the operator records **physical inventory events**, while the system derives the resulting inventory state.

Rather than manually updating inventory levels, the operator records only the activities that physically change the system. The inventory management system automatically calculates current inventory, historical consumption, operating costs, and future inventory requirements from those recorded events.

The inventory lifecycle consists of four primary activities:

1. Purchase raw nutrient chemicals.
2. Prepare a new nutrient stock solution batch.
3. Refill the production nutrient containers from prepared backup inventory.
4. Consume nutrients through automatic controller dosing.

Inventory is managed at three distinct levels:

- **Raw Chemical Inventory** – Dry chemicals used to prepare nutrient stock solutions.
- **Prepared Backup Inventory** – Mixed nutrient stock solutions stored for future production container refills.
- **Production Inventory** – Nutrient stock solutions connected directly to the dosing pumps and consumed during automatic nutrient dosing.

Each inventory level changes only through specific physical events:

| Inventory | Increased By | Decreased By |
|---|---|---|
| Raw Chemicals | Chemical Purchases | Batch Preparation |
| Prepared Backup Inventory | Batch Preparation | Production Container Refills |
| Production Inventory | Production Container Refills | Automatic Nutrient Dosing |

This architecture provides complete traceability from raw chemical purchase through final nutrient consumption while minimizing operator workload and eliminating manual inventory calculations.

Long-term inventory history supports batch traceability, cost analysis, consumption forecasting, and proactive nutrient purchasing without requiring duplicate data entry.

---

# Dry Nutrient Inventory

Dry nutrient inventory represents the raw chemical inventory used to prepare nutrient stock solution batches.

Each chemical is tracked independently from the time it is purchased until it is consumed during batch preparation. Inventory quantities are automatically updated as purchases and batch preparation events are recorded.

The system maintains inventory information for each chemical, including:

- Current quantity on hand
- Unit of measure
- Purchase history
- Supplier
- Current unit cost
- Inventory value
- Minimum desired inventory level
- Reorder quantity

The initial implementation will include the chemicals used by the MasterBlend nutrient recipe:

- MasterBlend 4-18-38
- Calcium Nitrate
- Magnesium Sulfate (Epsom Salt)

Future nutrient formulations may introduce additional chemicals without requiring changes to the inventory architecture.

---

# Nutrient Purchases

Nutrient purchases increase the available inventory of raw chemicals.

Each purchase is recorded as a single inventory transaction containing one or more purchased chemicals. This allows both individual chemical purchases and bundled nutrient kits to be handled using the same inventory workflow while maintaining accurate inventory records for each raw material.

The following information is recorded for each purchase:

- Purchase date
- Vendor
- Product description
- One or more purchased chemicals
- Quantity of each chemical
- Unit of measure
- Purchase cost of each chemical (when available)
- Total purchase cost
- Lot or batch number (optional)
- Operator notes (optional)

Current vendors include:

- Amazon
- Walmart

When a bundled nutrient kit is purchased, each included chemical is added individually to raw inventory. Whenever possible, the actual purchase cost of each chemical is recorded to provide accurate inventory valuation, nutrient batch costing, and long-term operating cost analysis.

If only the total purchase price of the kit is available, the system allocates the total cost among the included chemicals in proportion to their packaged quantities. This provides a consistent estimated unit cost until actual component pricing is available.

---

# Nutrient Batch Management

Nutrient batch preparation converts raw chemical inventory into prepared backup nutrient stock solution inventory.

Each batch is recorded as a separate production event, providing complete traceability between the purchased raw chemicals and the prepared stock solutions used by the hydroponic controller.

When a new batch is prepared, the system:

- Creates a unique batch record.
- Records the batch preparation date.
- Records the nutrient formulation used.
- Records the quantity of stock solution produced.
- Records the raw chemicals consumed.
- Automatically deducts the consumed quantities from raw chemical inventory.
- Calculates the batch production cost.
- Increases the available prepared backup inventory.
- Preserves complete batch traceability for future inventory and cost analysis.

Each prepared batch remains identifiable throughout its lifecycle until it has been completely transferred into production nutrient containers.

Detailed mixing procedures, measurements, and safety practices are documented separately in the **Nutrient Solution Mixing SOP** and are not duplicated here.

---

# Stock Solution Inventory

Prepared stock solution inventory consists of two distinct inventory levels:

- **Prepared Backup Inventory** – Freshly prepared nutrient stock solutions available for future use.
- **Production Inventory** – Nutrient stock solutions contained within the controller dosing reservoirs and available for immediate automatic dosing.

## Prepared Backup Inventory

Prepared backup inventory is created during nutrient batch preparation and remains in storage until transferred into a production container.

Each backup batch maintains:

- Batch identifier
- Batch preparation date
- Nutrient formulation
- Batch production cost
- Quantity prepared
- Quantity remaining
- Assigned production container (when transferred)

## Production Inventory

Production inventory consists of the Part A and Part B containers connected directly to the dosing pumps.

Each production container maintains:

- Current batch identifier
- Container capacity
- Empty container weight
- Full container weight
- Current measured weight
- Estimated remaining volume
- Percent remaining

When a production container is refilled, inventory is transferred from the prepared backup inventory to the production container while preserving complete batch traceability.

---

# Manual Inventory Updates

Under normal operation, inventory is updated automatically from recorded physical events and does not require manual adjustment.

Manual inventory updates are intended only for inventory verification, reconciliation, or recovery following unexpected events such as spills, measurement errors, or system maintenance.

When performed, the operator records the current weight of the production nutrient containers. The system compares the measured inventory with the calculated inventory and reports any significant discrepancy.

Routine inventory management is performed through:

- Nutrient purchases
- Nutrient batch preparation
- Production container refills
- Automatic nutrient dosing

Future versions of the system may incorporate permanently installed load cells to automate inventory verification and eliminate manual measurements.

---

# Automatic Inventory Updates

The inventory management system automatically updates inventory levels whenever a recorded physical event changes the state of the nutrient inventory.

No manual inventory calculations are required during normal operation.

Automatic inventory updates occur after:

- Recording a nutrient purchase
- Completing a nutrient batch
- Refilling a production nutrient container
- Automatic nutrient dosing
- Manual nutrient dosing

For each event, the system updates the appropriate inventory levels, preserves complete inventory traceability, and records the resulting inventory history for future analysis.

Future enhancements may include automatic verification of production inventory using permanently installed load cells to compare measured inventory against calculated inventory.

---

# Future Load Cell Monitoring

Future versions of the nutrient inventory system may incorporate load cells beneath the production nutrient containers to provide automatic inventory verification.

Potential benefits include:

- Continuous production inventory monitoring
- Automatic inventory reconciliation
- Early leak or abnormal consumption detection
- Improved nutrient consumption analysis
- Elimination of manual inventory verification

Load cells are considered an enhancement to inventory verification only. The inventory system will continue to derive inventory primarily from recorded physical events, with load cells providing independent confirmation of calculated inventory levels.

---

# Inventory Forecasting

Inventory forecasting uses current inventory levels and historical consumption data to estimate future nutrient requirements.

The objective is to provide sufficient advance notice to prepare additional nutrient batches or purchase raw chemicals before inventory becomes critically low.

Forecast information may include:

- Estimated remaining production inventory
- Estimated remaining backup inventory
- Estimated batches remaining
- Estimated days of operation remaining
- Recommended date to prepare the next nutrient batch
- Recommended raw chemical purchases
- Low inventory notifications

Forecasts are based on current inventory levels and recent nutrient consumption trends and will continue to improve as additional operating history is collected.

---

# Dashboard Integration

The nutrient inventory dashboard provides a real-time summary of inventory status and highlights any actions required to maintain uninterrupted operation.

The dashboard may include:

- Raw chemical inventory levels
- Prepared backup inventory status
- Production container inventory (Part A and Part B)
- Active nutrient batch
- Current batch cost
- Estimated remaining batches
- Estimated operating days remaining
- Recommended time to prepare the next nutrient batch
- Raw chemical purchase recommendations
- Low inventory and reorder notifications

The dashboard is intended to provide operators with sufficient information to maintain nutrient inventory without reviewing individual purchase records, batch history, or inventory transactions.

---

# Database Design

The nutrient inventory system uses database records to preserve purchase history, batch traceability, inventory movement, consumption, and cost information.

This document defines the functional ownership of the nutrient inventory data. Detailed table structures, columns, relationships, indexes, and database views are documented separately in **01 – Database Design**.

Related database objects include:

- `ingredients`  
  Defines the raw chemicals used to prepare nutrient stock solutions.

- `inventory_ledger`  
  Records inventory increases, decreases, transfers, adjustments, and the event responsible for each change.

- `nutrient_batches`  
  Records each prepared nutrient stock solution batch, including its identifier, preparation date, quantity produced, and calculated cost.

- `nutrient_batch_ingredients`  
  Records the raw chemical quantities and costs consumed by each prepared batch.

- `dry_chem_purchases_legacy`  
  Preserves historical dry chemical purchase records created before the current inventory architecture.

The database supports the complete inventory lifecycle:

    Nutrient Purchase
            ↓
    Raw Chemical Inventory
            ↓
    Nutrient Batch Preparation
            ↓
    Prepared Backup Inventory
            ↓
    Production Container Refill
            ↓
    Production Inventory
            ↓
    Nutrient Dosing

Inventory balances displayed in Home Assistant are derived from recorded inventory events rather than maintained through routine manual edits.

The database design must preserve:

- Complete transaction history
- Raw chemical purchase traceability
- Nutrient batch traceability
- Backup-to-production inventory transfers
- Automatic and manual dosing consumption
- Ingredient and batch cost calculations
- Historical records when database structures are revised

Implementation details are documented in:

- **01 – Database Design**

---

# Future Enhancements

Potential future enhancements include:

- Automated purchase reminders based on forecast inventory levels
- Vendor price comparison and historical cost trends
- Barcode or QR code support for inventory transactions
- Integration with online supplier catalogs

---

# Navigation

**Previous**

- [06 – Monitoring & Notification System](06-monitoring-and-notification-system.md)

**Next**

- [99 – Disaster Recovery](99-disaster-recovery.md)

**Related Documentation**

- [00 – System Overview](00-system-overview.md)
- [01 – Database Design](01-database-design.md)
- [05 – Nutrient Management & EC Control](05-nutrient-management-and-ec-control.md)
- [Nutrient Solution Mixing SOP](sop/hydroponics-nutrient-solution-mixing.md)

---

# Revision History

| Date | Revision | Description |
|---|---|---|
| 2026-07-27 | 0.2 | Expanded into a complete nutrient inventory management design document. Documented inventory architecture, purchasing, batch management, production inventory, forecasting, dashboard integration, and database responsibilities. |
| 2026-07-01 | 0.1 | Initial document outline. |

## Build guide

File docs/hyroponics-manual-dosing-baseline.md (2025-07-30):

# Hydroponics Dosing Session Summary

**Date**: 2025-07-30 02:31

**Tank Volume (gallons)**: 22.3

**Total Nutrients Added (mL)**: 150 A + 150 B = 300 mL

**Estimated Ratio**: 13.5 mL/gal

**Target EC**: 1.8 – 2.0 mS/cm

**Final EC (Bluelab)**: 2.0–2.2 mS/cm (bouncing)

**Final TDS Voltage**: 2.324 V (stable)

**Notes**: Initial EC was 0.4 mS/cm. 
Three manual override doses were administered (100 + 100 + 50 mL per A/B).
Circulation time allowed between doses to ensure mixing.
System currently reading within target range.
Use this as a baseline for future dosing.

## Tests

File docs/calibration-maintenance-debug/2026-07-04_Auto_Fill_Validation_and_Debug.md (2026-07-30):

# Auto Fill Validation & Debug Log
**Date:** 2026-07-04

> **Purpose**
>
> This is a working engineering log. Nothing in this document is considered
> permanent design documentation until the issue is fixed and verified.
> Items are intentionally recorded as observations, theories, bugs, and
> action items. Once verified, the permanent documentation will be updated.

---

# Test Objective

Validate the complete automatic fill cycle after changing the delay from 2 minutes to 30 minutes.

Test included:

- Auto-fill trigger
- 5-minute debounce
- 30-minute dwell
- Automatic fill
- Automatic nutrient dosing
- Notifications
- Event logging
- Inventory tracking
- Manual ESP Override dosing
- EC correction

---

# Successful Results

## PASS - Auto Fill Trigger

- Tank dropped below threshold.
- 5-minute debounce worked.
- Auto Fill Scheduled notification generated.

Status: ✅ VERIFIED

---

## PASS - 30 Minute Delay

- Fill started after approximately 30 minutes.

Status: ✅ VERIFIED

---

## PASS - Automatic Fill

- Fill started automatically.
- Fill stopped correctly.
- Approximately 9.85 gallons added.

Status: ✅ VERIFIED

---

## PASS - Flow Meter Calibration Verification

### Purpose

Verify that reverting the fill flow meter calibration back to **1690 pulses/gal**
corrected the fill volume reporting error discovered during the previous auto-fill.

### Previous Test (2026-06-28)

Tank Volume (start): 10.7 gal

Tank Volume (end): 20.4 gal

Database Record:

- Water Added: 11.37 gal
- Dose A: 114 mL
- Dose B: 114 mL

### Conclusion

Flow meter calibration was determined to be over-reporting the amount of water added.

A separate **1-gallon manual water addition** was performed and confirmed that the
tank volume calculation is reasonable. This isolated the issue to the flow meter
calibration rather than the tank volume calculation.

### Action - Investigate ESPHome Flow Meter Calibration

See:

- `esphome/hydroponics-patio-esp32.yaml`
  - Flow Meter Calibration comments dated **2026-06-28**

### Today's Verification (2026-07-04)

Tank Volume (start): 11.1 gal

Tank Target: 21.0 gal

Expected Fill: 9.9 gal

Flow Meter Recorded: 9.85 gal

Tank Volume (end): 20.6 gal

### Result

✅ **PASS**

The reverted **1690 pulses/gal** calibration produced a measured fill within **0.05 gallons** of the expected fill. The previous calibration issue is considered resolved.

Status: VERIFIED

---

## EC Calibration

During auto-fill validation, additional EC reference data was collected.

See:

`docs/calibration-maintenance-debug/EC_TDS_CALIBRATION_HISTORY.md`

Reason:

The automatic fill dose restored nutrients proportional to the water added but
did not restore the tank to the target EC of 2.0. A manual correction was
required to obtain another calibration reference point.

# Calibration History From This Test

| Time | Event | Tank | Probe | Handheld EC |
|---|---|---:|---:|---:|
| 09:10 | Before fill | 11.7 gal | 1.799 V | 1.70 |
| 12:59 | After auto fill | 20.6 gal | 1.752 V | 1.60 |
| 13:37 | Before correction | 20.6 gal | 1.774 V | 1.70 |
| 14:17 | After +50/+50 mL | 20.5 gal | 1.961 V | 2.00 |

---

# Decisions Made Today

- Maintenance Auto Dose remains disabled.
- Auto Fill controller successfully completed validation.
- Fill dosing remains proportional to gallons added until further evidence suggests otherwise.
- EC correction should continue using post-fill maintenance dosing.
- Permanent documentation will NOT be updated until all fixes are implemented and verified.

---

# Working Action List

## HIGH

- [ ] Repair Event History Dashboard
- [ ] Fix Auto Fill Logged notification values
- [ ] Fix Maintenance notification tank volume
- [ ] Determine inventory update sequence
- [ ] Redesign Maintenance Auto Dose controller
- [ ] Add Controller State indicator
- [ ] Investigate Manual ESP Override anomaly

## MEDIUM

- [ ] Fix duplicate notifications
- [ ] Improve dashboard status cards
- [ ] Improve Event Notes
- [ ] Improve event rendering by event type

---

# Notes

This document is intentionally a working engineering notebook.

Nothing contained here should be considered permanent design documentation until each issue has been fixed, tested, and verified.

---

# Issues Discovered

# ISSUE-001 - Event History Dashboard / Formatter

### Problem

The Browse for Event cards were using a generic formatter that displayed
irrelevant fields for different event types.

Examples:

- EC_REFERENCE displayed Fill 0.00 gal and Dose 0 mL.
- NOTE events displayed unrelated fill information.
- Event titles did not clearly identify the type of operation performed.

### Changes Made

- Added event-type-specific formatting in the Node-RED
  **Format Recent Activity** function.
- Updated `v_hydro_recent_activity` to expose `meter_value`
  and `meter_units` for EC reference events.
- EC_REFERENCE cards now match the EC Reference History display.
- NOTE events now display only note-related information.

### Enhancement Requested

Improve event titles to identify the operation performed rather than only
displaying the generic event type.

Examples:

Current:

```
#59 — DOSE
```

Preferred:

```
#59 — Auto Fill
#60 — Manual Fill
#61 — ESP-Override Dose
#62 — Auto Maintenance Dose
#63 — EC Reference
#64 — Field Note
```

The event title should immediately identify the workflow that created the
record while preserving the event number.

### Status

🟡 PARTIALLY COMPLETE

Formatting issues have been corrected.

Event title naming remains to be implemented.

---

# ISSUE-002 - Auto Fill Completion Notifications

Priority: HIGH

### Observed

The automatic fill completed successfully, but the completion notifications
contained inconsistent information.

### Notifications Received (Newest First)

#### Maintenance Cycle Complete

(Source: Node-RED Flow-1 Hydroponics Cycle Manager)

```
auto FILL completed

Water Added: 9.85 gal
Dose A: 98 mL
Dose B: 98 mL
System Volume: 11.1 gal
TDS: 1.800 → 1.751
```

Issues:

- Water added is correct.
- Dose A/B values are correct.
- **System Volume is incorrect.**
  - Reported: **11.1 gal**
  - Expected: **20.5–20.6 gal** (post-fill volume)

---

#### 🤖 Auto Fill Logged

```
9.85 gallons filled
Mode: Auto

Dose A: 0.0 mL
Dose B: 0.0 mL
```

Issues:

- Water added is correct.
- Dose values are incorrect.
- This notification may no longer provide useful information now that the
  Maintenance Cycle Complete notification contains more complete information.

---

#### 🤖 Auto Fill Scheduled

```
Tank is low (11.2 gal)...

Auto fill will begin...
```

This notification behaved as expected and should be retained.

### Current Interpretation

The fill itself executed correctly.

The problems appear to be in the notification data rather than the controller.

Evidence suggests different notifications are using different snapshots of the
controller state.

Examples:

- Water Added appears to be correct.
- Dose values are correct in one notification but zero in another.
- System Volume is using the pre-fill value instead of the final tank volume.

This suggests the notifications are being generated at different points in the
workflow or are reading different entities.

### Fill Cycle Entity Inventory

| Entity | Purpose | Current Status | Notes |
|---|---|---|---|
| sensor.outside_tank_gallons | Current calculated tank volume | ✅ Active | Used before and after fill. |
| sensor.outside_filtered_tank_gallons | Legacy filtered tank volume | ⚠ Investigate | Used last year when the scale was noisy. Current HX711 data appears stable enough that this may no longer be needed. |
| input_number.tank_full_target | Target full tank volume | ✅ Active | Used to determine fill target. |
| input_number.auto_fill_threshold_gallons | Auto-fill trigger threshold | ✅ Active | Starts 5-minute debounce. |
| input_number.outside_manual_fill_gallons | Requested fill amount | ✅ Active | Manual fill target. |
| sensor.hydroponics_patio_esp32_fill_gallons | ESP flow meter total during fill | ✅ Active | Resets after fill. Represents water added. |
| sensor.hydroponics_patio_esp32_last_fill_gallons | Last fill amount | ⚠ Unknown | Lost after ESP reboot. Candidate to replace with HA helper. |
| input_datetime.auto_fill_threshold_crossed_at | Low tank detected | ✅ Active | Used for debounce timing. |
| input_datetime.outside_tank_fill_started | Fill start timestamp | ✅ Active | Last updated 2026-07-04 12:39:07. |
| input_datetime.outside_tank_fill_stopped | Fill stop timestamp | ✅ Active | Last updated 2026-07-04 12:41:07. |
| sensor.outside_tank_last_fill_duration | Last fill duration | ✅ Active | Derived from timestamps. |
| automation.outside_tank_fill_log_and_notify_auto_only | Main Auto Fill workflow | ✅ Active | Primary automation under investigation. |
| automation.pre_fill_manual_dose_a_b_based_on_target_gallons | Pre-fill nutrient dose | ✅ Active | Runs before fill. |
| automation.esp_override_tank_fill_log | ESP Override fill logging | ✅ Active | Manual/ESP override workflow. |
| automation.outside_tank_fill_manual_logging | Manual fill logging | ✅ Active | Separate from Auto mode. |
| automation.cancel_auto_fill_on_mode_change | Cancel pending auto fill | ✅ Active | Cancels scheduled fill if mode changes. |
| input_datetime.tank_refill_completed | Legacy helper | ⚠ Investigate | Last updated 2025-07-13. Appears unused. |

### Observation

The current HX711 tank scale appears sufficiently stable for automatic fill control.

The existing 5-minute low-level debounce provides the necessary protection against transient level changes, reducing the need for a separately filtered tank volume sensor.

The continued need for `sensor.outside_filtered_tank_gallons` should be reevaluated after additional operational testing.

## Fill Cycle Model

The system uses four different gallon values that must not be confused.

1. Starting Tank Volume (`sensor.outside_tank_gallons`)
2. Target Tank Volume (`input_number.tank_full_target`)
3. Water Added (`sensor.hydroponics_patio_esp32_fill_gallons`)
4. Ending Tank Volume (`sensor.outside_tank_gallons` after fill)

Several notification and logging bugs discovered on 2026-07-04 were caused by mixing these values.

### Questions To Investigate

- [x] Which automation generates the **🤖 Auto Fill Logged** notification?
  - `automation.outside_tank_fill_log_and_notify_auto_only`

- [x] Which process generates the **Maintenance Cycle Complete** notification?
  - Node-RED Flow-1 Hydroponics Cycle Manager

- [x] Which process generated the bad legacy CSV row?
  - `automation.outside_tank_fill_log_and_notify_auto_only`

- [ ] Which entity/value supplies **System Volume** in the Node-RED completion notification?
  - Current evidence suggests it is using the pre-fill tank volume.

- [ ] Should Node-RED Flow-1 report both:
  - Starting Volume
  - Final Volume

- [ ] Are any remaining notifications using stale helper values?

### Fixes Applied

- Removed legacy **🤖 Auto Fill Logged** notification from
  `automation.outside_tank_fill_log_and_notify_auto_only`.

- Removed legacy CSV write to `notify.file_2`.

- Fill-stopped branch now only:
  - timestamps fill stop
  - resets `input_boolean.allow_auto_fill`

- Updated Node-RED Flow-1 completion notification.
  - FILL events now distinguish between:
    - Starting Volume
    - Calculated Final Volume
  - DOSE events continue to report System Volume.

### Verification

⏳ Pending next automatic fill cycle.

Expected notification:

auto FILL completed

Water Added: xx.xx gal
Dose A: xx mL
Dose B: xx mL
Starting Volume: xx.x gal
Calculated Final Volume: xx.x gal
TDS: x.xxx → x.xxx

### Remaining Problem

The next automatic fill must verify that the updated Node-RED notification now reports:

- Starting Volume
- Calculated Final Volume

instead of the misleading `System Volume`.

The larger remaining issue is that dashboard values sourced directly from ESPHome sensors are transient and are lost after ESP reboot/reflash.

Persistent “last completed cycle” values need to be stored in Home Assistant helpers and displayed through read-only template sensors.

Status: IMPLEMENTED - pending next fill verification

### ESPHome Helper Naming Fix

Validation passed.

Changed ESPHome post-fill helper writes to:

- `input_datetime.outside_tank_fill_stopped`
- `input_number.outside_tank_last_fill_gallons`

Status: IMPLEMENTED - pending next fill verification

### Verification - 2026-07-06 Short Auto Fill

Chronological test sequence:

1. EC reference before fill:
   - Time: 2026-07-06 08:33
   - EC: 1.70
   - Probe: 1.716 V
   - Tank: 17.8 gal
   - Temp: 67.2°F

2. Auto Fill Scheduled notification:
   - Tank low: 17.8 gal
   - Fill scheduled for 09:00
   - Notification worked, but wording should change from:
     `Turn Off input_boolean.allow_auto_fill`
     to:
     `Turn Off Auto Fill Gate`

3. Auto Fill - Auto Dose completed.

4. Node-RED completion notification reported:
   - Water Added: 4.28 gal
   - Dose A: 43 mL
   - Dose B: 43 mL
   - Starting Volume: 17.7 gal
   - Calculated Final Volume: 22.0 gal
   - TDS: 1.735 → 1.706

5. EC reference after fill:
   - Time: 2026-07-06 09:14
   - EC: 1.70
   - Probe: 1.753 V
   - Tank: 21.1 gal
   - Temp: 67.8°F
   - Note: After maintenance cycle complete on short autofill

### Validation Result

The stale **Auto Fill Logged** notification was successfully removed.

Node-RED notification now correctly distinguishes:

- Water Added
- Starting Volume
- Calculated Final Volume

The notification still needs terminology cleanup:

- Rename title from **Maintenance Cycle Complete**
  to **Auto Fill - Auto Dose Complete** when event type is `FILL`.

The calculated final volume was:

`17.7 + 4.28 = 22.0 gal`

Actual post-fill tank reading was:

`21.1 gal`

This difference should be noted but not treated as a failure yet because the tank scale may not have fully stabilized at notification time or the calculation uses pre-fill + flow-meter value rather than final tank weight.

### Dashboard Observations During 2026-07-06 Auto Fill

Screenshots captured the live dashboard state during the cycle.

Observed sequence:

1. Auto Fill Scheduled notification was correct, but wording should be updated:
   - Current: `turn Off the toggle: input_boolean.allow_auto_fill`
   - Preferred: `turn Off Auto Fill Gate`

2. Fill start timestamp updated correctly at fill start.

3. While filling, Fill Duration temporarily displayed a large negative value because:
   - fill start had updated to the current cycle,
   - fill stop still contained the previous cycle timestamp.

4. After fill completed:
   - Fill Ended updated correctly.
   - Fill Duration corrected to 0.8 min.
   - Gallons Measured showed 4.33 gal.
   - Last Fill Gallons showed 4.28 gal.

5. Auto dose sequence completed:
   - Dose A: 42.79 mL
   - Dose B: 42.79 mL
   - Pump A Runtime eventually showed 26.99 s.
   - Pump B Runtime eventually showed 26.00 s.
   - Last Dose A and Last Dose B updated to 7/6/2026 9:01 AM.

### Status

What was accomplished

Controller Modes

✅ Renamed operating modes to reflect actual behavior:
Auto Fill - Auto Dose
Manual Fill - Auto Dose
ESP-Override
✅ Updated dashboards.
✅ Updated conditional cards.
✅ Updated button-card colors.
✅ Updated Node-RED mode normalization with backward compatibility.

Flow-1 Cycle Manager

✅ Proper documentation added.
✅ Better separation of responsibilities.
✅ Notification titles now driven by controller mode and event type.

Notifications

✅ Removed obsolete Auto Fill notification.
✅ Removed legacy CSV write.
✅ Fixed fill summary to distinguish:
Water Added
Starting Volume
Calculated Final Volume

Persistence

✅ Last fill gallons now stored in a persistent HA helper.
✅ ESPHome helper names corrected.
✅ Identified the next phase of migrating "last completed cycle" values out of transient ESP sensors.

Documentation

✅ Node documentation standardized:
Purpose
Responsibilities (where appropriate)
Revision History
✅ ISSUE-002 is now largely verified with a real production fill.

### Related Files

Required:

- patio_controller.yaml
- patio_dosing_controls.yaml
- db_history_dashboard.yaml

As Needed:

- Home Assistant automations related to Auto Fill and Auto Dose
- Hydroponics_Cycle_Manager.json
- 05-nutrient-management-and-ec-control.md

### Components Affected

- ESPHome
- Home Assistant
- Node-RED
- MariaDB
- Dashboard
- Documentation

### Final Result

The notification redesign was successfully implemented and verified.

Legacy notifications and CSV logging were removed.

Node-RED now reports:

- Water Added
- Starting Volume
- Calculated Final Volume
- Dose A
- Dose B
- TDS Before/After

Remaining enhancements involving persistent dashboard state were moved to ISSUE-008.

### Status

**CLOSED – VERIFIED**

---

# ISSUE-003 - Inventory Synchronization

Priority: MEDIUM

Observed:

Inventory appeared unchanged after fill.

Later inventory reflected approximately:

98 mL Auto Fill
+
50 mL Manual Dose

Need to determine:

- when inventory updates
- who updates inventory
- why update timing is inconsistent

### Inventory Recovery

Container tare (matching container):
190 g

Cap:
6 g

Measured densities:

Part A
241 g / 200 mL = 1.205 g/mL

Part B
233 g / 200 mL = 1.165 g/mL

Gross weights:

Part A = 3500 g

Part B = 3300 g

Current inventory values require verification before permanent correction.

---

### Related Files

Required:

- batch_building.yaml
- patio_controller.yaml
- patio_dosing_controls.yaml
- db_history_dashboard.yaml

As Needed:

- Home Assistant automations related to Auto Fill and Auto Dose
- Hydroponics_Cycle_Manager.json
- 05-nutrient-management-and-ec-control.md

### Components Affected

- ESPHome
- Home Assistant
- Node-RED
- MariaDB
- Dashboard
- Documentation

Status: OPEN

---

# ISSUE-004 - ESP Override Manual Dose Anomaly

Priority: HIGH

### Observed

During an attempted manual ESP Override dose, the system entered an uncertain state.

Sequence:

- User intended to perform a 50 mL Part A manual dose.
- User pressed the **Motor Start/Stop** control instead of the **50 mL Dose** control.
- Dashboard timer continued counting.
- Pump state became questionable.
- Manual switch appeared responsive.
- Laptop/Wi-Fi issue occurred at the same time.
- System was powered down as a precaution.
- After recovery, a verified ESP Override dose was performed successfully.

### Notifications Observed

Unverified / anomaly event:

- ESP Override Dose A Logged
- Timestamp: `2026-07-04 01:12 PM`
- Duplicate notification received.
- Maintenance Cycle Complete also reported an ESP Override dose completion.
- Actual dose completion is uncertain.

Verified recovery event:

- ESP Override Dose A Logged
- Timestamp: `2026-07-04 01:58 PM`
- Dose A: 50.0 mL

- ESP Override Dose B Logged
- Timestamp: `2026-07-04 01:59 PM`
- Dose B: 50.0 mL

- Maintenance Cycle Complete
- System Volume: 20.6 gal
- TDS: 1.778 → 1.940

### Current Interpretation

The duplicate notification may not be a standalone notification bug.

It may have been caused by the same manual dosing anomaly:

- wrong dashboard control used,
- possible Wi-Fi/UI synchronization issue,
- interrupted dose sequence,
- system shutdown during uncertain state.

The important issue is not simply the duplicate notification. The issue is that the controller reported completion for a dose that may not have completed.

### Questions To Investigate

- [ ] Did the Motor Start/Stop control bypass the normal 50 mL dose script?
- [ ] Does the runtime counter continue if the pump is manually stopped?
- [ ] Can the ESPHome script report dose completion after interruption?
- [ ] Can Node-RED log a dose based on planned runtime instead of actual pump runtime?
- [ ] Did Home Assistant or Node-RED send duplicate notifications, or did the same event get emitted twice?
- [ ] Should manual pump start/stop be hidden or protected when dosing automation is active?

### Required Fix / Improvement

Manual pump controls must fail safe.

The system should not report a completed dose unless the dose script actually completed successfully.

If a manual dose is interrupted, the system should record it as:

```text
INTERRUPTED / UNKNOWN DOSE
```

Status: OPEN

---

# ISSUE-005 – Controller State Visibility

**Priority:** HIGH

### Current State

The dashboard does not yet accurately represent what the hydroponics controller
is doing at any given time.

Several independent Home Assistant automations, ESPHome scripts, timers, and
Node-RED flows may be active, but the dashboard currently provides only partial
or misleading status.

As a result, the operator cannot always quickly determine whether the controller
is:

* Idle
* Waiting
* Filling
* Dosing
* Mixing
* Complete
* Blocked
* Faulted

---

### Problems Observed

Examples encountered during development:

* Auto Dose card indicated **ON** while the automation itself was disabled.
* Controller appeared idle while actually waiting for the Auto Fill dwell period.
* Maintenance dosing was executing while the dashboard still showed **Ready**.
* Difficult to distinguish between:

  * Waiting for maintenance debounce
  * Waiting for scheduled fill
  * Waiting for nutrient mixing
  * Waiting before the next maintenance dose
* No indication that ESPHome was actively executing Pump A, Pump B, or a
  maintenance dose request.

---

### Design Goal

Create a single operator-facing controller state that accurately represents what
the hydroponics system is doing at any given time.

The dashboard should answer one question immediately:

> **What is the controller doing right now?**

without requiring the operator to inspect Home Assistant automations, ESPHome
logs, or Node-RED.

---

### Desired Visible States

Examples include:

* Idle
* Waiting for Low-Level Debounce
* Auto Fill Scheduled
* Filling
* Calculating Fill Dose
* Dosing Nutrient A
* Waiting Between Pumps
* Dosing Nutrient B
* Mixing
* Waiting for Maintenance Recheck
* Maintenance Dosing
* Cycle Complete
* Cancelled
* Blocked
* Fault
* Calibration Mode
* ESP-Override

The final state model may change during implementation.

---

### Engineering Decisions

The controller state design must preserve the existing separation of
responsibilities.

#### Home Assistant

Home Assistant owns:

* Operator configuration
* Maintenance dosing coordination
* Auto Fill coordination
* Dashboard presentation
* Controller state visibility
* Adjustable timing parameters

#### ESPHome

ESPHome remains responsible for:

* Physical pump outputs
* Fill solenoid control
* Pump sequencing
* Pump runtime
* Inter-pump delay
* Local execution safety gates

#### Node-RED

Node-RED remains responsible for:

* Completed-cycle logging
* Delayed post-mixing TDS capture
* Database writes
* Completion notifications

A configurable value should have one authoritative owner. Other components
should consume that value rather than defining duplicate independent settings.

---

### Configurable Timing Design

Four operating timing values were identified as operator-configurable.

#### Maintenance Debounce

Defines how long the maintenance-dose conditions must remain continuously valid
before a maintenance dose may begin.

**Default:** 5 minutes

**Owner:** `patio_dosing_controls.yaml`

#### Maintenance Mixing Time

Defines how long newly added nutrients are allowed to circulate before the
post-dose TDS value is evaluated.

This value may require adjustment if tank volume or circulation flow rates are
changed.

**Default:** 10 minutes

**Owner:** `patio_dosing_controls.yaml`

#### Next Maintenance Dose Offset

Defines the additional delay after the mixing period before another automatic
maintenance dose may begin.

**Default:** 60 seconds

**Owner:** `patio_dosing_controls.yaml`
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

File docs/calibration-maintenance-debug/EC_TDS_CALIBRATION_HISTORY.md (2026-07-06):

# EC / TDS Calibration History

## Purpose

This document is the engineering notebook for calibration of the hydroponics
EC/TDS measurement system.

It records:

- Hardware changes
- Firmware changes affecting EC measurement
- Calibration equations
- Handheld EC reference measurements
- Probe voltage observations
- Temperature effects
- Calibration decisions
- Outstanding questions

Permanent design documents should reference this file rather than duplicate
its contents.

---

# Current ESPHome Calibration

## ADS1115 Configuration

```yaml
# TDS meter input via ADS1115 A0
- platform: ads1115
  ads1115_id: ads1115_outside
  multiplexer: 'A0_GND'
  gain: 4.096          # Updated 2026-07-27 from 2.048
  id: tds_raw
  name: "TDS Raw"
  update_interval: 2s
  accuracy_decimals: 3
  unit_of_measurement: "V"
```

## Current EC Estimation

```cpp
return 0.423 * v * v + 0.132 * v - 0.043;
```

Status:

⚠ Experimental

Purpose:

Dashboard estimate only.

The handheld EC meter remains the calibration standard.

---

# Hardware Changes

## 2026-07-03

### ADS1115 Supply Voltage

Changed ADS1115 VDD:

**5.0 V → 3.3 V**

### Reason

The ADS1115 was changed to operate from the same **3.3 V supply** as the ESP32.

This change was made to improve compatibility between the ADC and ESP32 logic levels and to eliminate the possibility of exposing the ESP32 to voltages above its recommended input range.

### Current Status

The change has **not yet been fully characterized**.

Current observations indicate:

- The TDS probe continues to respond correctly.
- The raw probe voltage changed as expected after the hardware modification.
- Additional handheld EC reference measurements are being collected to determine whether the EC estimation model requires recalibration.

### Open Items

- [ ] Verify the TDS probe output remains within the valid ADS1115 input range.
- [ ] Verify the probe output cannot exceed safe ESP32 voltage limits.
- [ ] Determine whether changing ADS1115 VDD affects the existing EC estimation model.

# Known Characteristics

## Temperature

Current observations indicate:

- Probe voltage changes with water temperature.
- Raw probe voltage is not currently a direct measure of nutrient concentration.
- Temperature compensation is still under investigation.

---

# Calibration Sessions

## 2026-07-04

### Purpose

Validate automatic fill behavior and collect additional EC calibration data.

### Reference Measurements

| Time | Event | Tank | Temp | Probe | Handheld EC |
|---|---|---:|---:|---:|---:|
|09:10|Before Fill|11.7|73.1°F|1.799|1.70|
|12:59|After Auto Fill|20.6|70.3°F|1.752|1.60|
|13:37|Before Correction|20.6|71.9°F|1.774|1.70|
|14:17|After +50/+50|20.5|73.5°F|1.961|2.00|

### Observations

Automatic fill restored nutrients proportional to the water added.

A manual correction of:

- 50 mL Part A
- 50 mL Part B

returned the tank to:

- Handheld EC = 2.00
- Probe Voltage = 1.961 V

This establishes another calibration reference point.

No changes were made to the ESPHome EC equation.

---

# Open Questions

- Determine temperature compensation.
- Validate EC estimation equation.
- Continue collecting handheld reference data.
- Determine operating voltage range over seasonal temperature changes.

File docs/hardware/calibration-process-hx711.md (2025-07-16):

# 🧪 Calibration Process: Why Use a Template Sensor

This hydroponics system uses a weight-based method to monitor tank volume via a 4-load-cell platform and HX711 amplifier. While ESPHome supports inline sensor filtering and basic calculations, **precise tank calibration requires greater flexibility** than is practical inside a microcontroller’s firmware.

---

## 🚫 Problem with On-Device Calibration

Originally, calibration was performed directly in ESPHome using a formula like:

```yaml
float gallons = (raw + offset) * scale_factor;
```

However, this approach has two major drawbacks:

1. **Reflashing Required:**  
   Any adjustment to calibration constants (offset or slope) required editing the YAML and reflashing the device — inconvenient for outdoor equipment or remote management.

2. **Limited Flexibility for Multi-Point Calibration:**  
   The true tank behavior is not always linear. A single scale factor is often insufficient, especially near the bottom of the tank where measurement accuracy is most important.

---

## ✅ Why Template Sensor Calibration in Home Assistant

Instead of embedding gallon calculations in ESPHome, we send the raw HX711 value to Home Assistant and use a **template sensor** there.

### Benefits:

- 🔁 **No Reflashing Needed** — Calibration points can be updated from the Home Assistant UI  
- 🔢 **Multi-Point Curve Support** — Uses 6 calibration points from 0 to 25 gallons  
- 📉 **Dynamic Interpolation** — Calculates gallons using linear interpolation between known values  
- 🚨 **Safe Error Handling** — Skips calibration pairs where `raw == 0` to avoid false output

---

## 🪣 Emergency Calibration Procedure (5-Gallon Bucket)

To simplify field recalibration:
- A **5-gallon bucket** is used to fill the tank in increments
- At each 5-gallon mark, the current raw HX711 value is saved into a corresponding `input_number`
- These values are used by the Home Assistant template sensor for interpolation

> This process can be repeated **at any time** with no firmware changes.

---

## 🧾 Summary of Benefits

| Feature | ESPHome Inline Logic | Home Assistant Template |
|---|---|---|
| Change without reflashing | ❌ | ✅ |
| Support multiple calibration points | ❌ | ✅ |
| Recalibrate remotely | ❌ | ✅ |
| UI-based fine-tuning | ❌ | ✅ |

---

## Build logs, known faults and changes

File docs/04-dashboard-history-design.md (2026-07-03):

# Dashboard and History Design

**Revision:** 0.4
**Last Updated:** 2026-07-03
**Status:** Active Development / Production Components

---

# Purpose

The Home Assistant dashboard is intended to be the primary operator interface for the hydroponic vegetable garden.

Its purpose is to provide simple, task-oriented workflows for operating, monitoring, and maintaining the hydroponic system.

Routine operation should not require opening Node-RED, DBeaver, or MariaDB. Those tools are intended for development, engineering, and troubleshooting.

---

# Development Status

| Component | Status | First Working | Last Updated |
| --- | --- | --- | --- |
| Current Status Dashboard  | 🚧 Partial | 2026-06-26 | 2026-06-28 |
| Controller Mode Selection | ✅ Production | 2026-06-26 | 2026-06-28 |
| EC Reference Measurement  | ✅ Production | 2026-06-28 | 2026-07-03 |
| Hydro-History Browser | ✅ Production | 2026-06-29 | 2026-07-03 |
| EC Reference History | ✅ Production | 2026-07-03 | 2026-07-03 |
| Event Annotation | ✅ Production | 2026-06-30 | 2026-07-03 |
| Inventory Dashboard | ⏳ Planned | — | 2026-06-28 |
| Batch Building Workflow | ⏳ Planned | — | 2026-06-28 |
| Harvest Dashboard | ⏳ Planned | — | 2026-06-28 |

---

# Dashboard Philosophy

Every dashboard should answer three questions.

## 1. What is happening now?

Current operating conditions.

Examples:

* Tank volume
* Estimated EC
* Probe voltage
* Water temperature
* Flow rates
* Controller mode
* Pump status
* Automation status

---

## 2. What just happened?

Recent operational history.

Examples:

* Last fill
* Last nutrient dose
* Last EC reference check
* Last equipment event
* Last manual operation

The operator should never need DBeaver simply to determine recent system activity.

---

## 3. What needs attention?

The dashboard should highlight exceptions rather than overwhelming the operator with raw data.

Examples:

* Low inventory
* Batch nearly empty
* Flow alarm
* Sensor failure
* Equipment issue
* EC drift
* Upcoming nutrient batch requirement

---

# Dashboard Sections

The dashboard is expected to evolve into several functional areas.

## System Status

Daily operating information.

Examples:

* Tank level
* Estimated gallons
* Estimated EC
* Water temperature
* Flow rates
* Controller mode
* Pump status

---

## Recent Activity

Displays the most recent operational history.

Examples:

* Fill
* Dose
* Mode change
* EC reference measurement
* Equipment event
* Manual note

Initial implementation consists of a dedicated Hydro-History dashboard.

The Hydro-History dashboard is driven by Node-RED, which queries
`v_hydro_recent_activity`, formats the results, and provides them to
Home Assistant for display.

A dedicated EC Reference History panel supplements the Hydro-History browser.
Rather than displaying all hydroponic events, it displays only handheld EC
reference measurements used to calibrate the installed TDS probe and Estimated
EC model.

The EC Reference History panel is also generated by Node-RED and provides the
following information for each reference measurement:

* Handheld EC
* Probe voltage
* Tank gallons
* Water temperature
* Rainfall since the previous EC reference
* Estimated rainwater dilution
* Operator note

Current capabilities include:

* Browse newest to oldest events
* Page forward/back through history
* Select an individual event
* Display complete event details
* Edit operator notes
* Automatically refresh after saving an operator note
* View dedicated EC reference history without opening DBeaver

---

## Event Details

Selecting an event should display all recorded information associated with that event.

The information displayed depends on the selected event type.

Examples:

* Date and time
* Event type
* Tank gallons
* Fill amount
* Nutrient dose
* Probe voltage
* Estimated EC
* Water temperature
* Rainfall since previous EC reference
* Estimated rainwater dilution
* Flow readings
* Notes
* Operator Note

This allows investigation without manually querying the database while presenting
the information most relevant to the selected activity.

# History Browser Roadmap

The Hydro-History dashboard is being implemented in stages.

## Phase 1 — Database Connectivity

* Verify Home Assistant connectivity to MariaDB.
* Verify `v_hydro_recent_activity` can be queried.
* Verify Node-RED can retrieve and format recent activity.

Status: ✅ Complete

---

## Phase 2 — History Browser

* Display recent activity in Home Assistant.
* Browse newer and older history.
* Select an event.
* Display complete event details.

## Phase 2a — Event Selection

* Browse recent history
* Page forward/back through history
* Step forward/back one record
* Select a source-aware activity record
* Populate operator editing controls
* Edit existing operator notes
* Save annotation back to the correct source table
* Automatically refresh the browser after save
  
Status: ✅ Complete

---

## Phase 3 — Operator Workflows

Selected events may initiate workflows such as:

* Create standalone field note
* Optional field note date override
* Field note location/area context
* Equipment issue workflow
* Maintenance completed workflow
* Event detail popup (optional)
  
Status: 🚧 Partial (Field Notes complete; additional workflows pending)

---

# Operator Workflows

The dashboard should guide the operator through common hydroponic tasks.

Implementation details are documented separately in:

* `node-red/README.md`
* `home-assistant/packages/README.md`
* `docs/01-database-design.md`

## Current Production Workflows

| Workflow | Status | Purpose |
| --- | --- | --- |
| Measure EC | ✅ Production | Records a handheld EC reference measurement for comparison with the installed probe and Estimated EC model. |
| Hydro-History Browser | ✅ Production | Browse hydroponic activity history, view event details, and navigate recent system activity. |
| Event Annotation | ✅ Production | Add or edit operator notes for supported activity records directly from the History Browser. |
| EC Reference History | ✅ Production | Displays handheld EC reference history, rainfall context, and calibration data without using DBeaver. |
| Automatic Fill / Dose Logging | ✅ Production | Automatically records completed fill and nutrient dosing cycles in the maintenance history. |
| Standalone Field Note | ✅ Production | Creates a standalone NOTE event in `maintenance_log` with optional date and location context. |

## Planned Workflows

| Workflow | Purpose |
| --- | --- |
| Equipment Event | Record maintenance, repairs, leaks, and equipment failures. |
| Record Purchase | Record nutrient purchases and automatically update inventory. |
| Build Nutrient Batch | Create stock solution batches and update inventory. |
| Harvest Entry | Record harvested produce by season and planting position. |
| Waste Entry | Record crop losses and discarded produce. |

---

# Event Annotation

Operator notes may be attached to supported Hydro-History activity records, including `maintenance_log` records and EC reference records from `hydro_tds_reference_reading`.

The selected activity stores both the activity source and source ID, such as `maintenance_log:52` or `ec_reference:5`, so notes are written back to the correct database table.

Operational events record **what** happened.

They do not always explain **why** it happened.

Example:

Two fill events occurring within a few minutes of each other may indicate an equipment problem.

The dashboard should allow additional information to be attached after the event has occurred.

Examples:

* Hose clamp failure
* Pump tubing slipped
* Sensor cleaned
* Leak repaired
* Incorrect manual dose
* Equipment replaced

The original operational event remains unchanged.

Only the dedicated operator_note field may be edited after the event has been recorded.

This preserves the measured operational data while allowing additional human context to be attached later.

Instead, they become additional historical information linked to that event.

---

# Example Investigation

Observed history:

```text
08:10  Fill
08:14  Fill
```

The operator recognizes that two fills should never occur within such a short period.

Selecting either event allows additional context to be recorded.

Example:

```text
Equipment Failure

The circulating pump hose clamp failed.

The system correctly performed two fill-and-dose operations; however, the failed hose clamp allowed the water and nutrients to be pumped onto the ground instead of remaining in circulation.

Both fill-and-dose cycles were therefore lost.

The hose clamp was replaced and normal operation resumed.
```

The explanation is stored in the `operator_note` field associated with the selected activity record and is displayed alongside the event within the Hydro-History browser.

Depending on the selected activity, the note may be stored in either `maintenance_log` or `hydro_tds_reference_reading`.
This preserves both:

* The original measurements
* The explanation discovered during troubleshooting

# Field Notes

Not all operator notes are tied to a specific event.

Some notes document general field observations, maintenance actions, crop conditions, or system changes that are useful to the season history.

Examples:

* Added another layer of support netting
* Plants outgrew first trellis layer
* Cleaned sensor probes
* Replaced pump tubing
* Adjusted plant spacing
* Observed pest pressure
* Noted heat stress
* Repaired leak before next cycle

Field notes should be recorded as their own `NOTE` events in `maintenance_log`.

Unlike event annotations, field notes do not need to reference an existing fill, dose, harvest, or purchase event.

This allows the history dashboard to show both:

* automated system events
* operator-entered observations

Together, they provide a more complete operating history than automation alone.

---

# Design Goals

The dashboard should allow the operator to answer questions such as:

* What happened today?
* Why did the system fill?
* Why did it dose?
* When was the last EC reference check?
* Is inventory running low?
* What equipment problems have occurred?
* Which nutrient batch is currently in use?
* Which crops are producing the most?

without writing SQL or opening database tools.

---

# Long-Term Vision

The dashboard should evolve from a collection of sensor cards into a complete hydroponic management interface.

Nearly every routine interaction with the hydroponic system should eventually occur through Home Assistant.

ESPHome will continue to provide real-time controller logic, Node-RED will execute workflow automation, and MariaDB will maintain the permanent historical record.

Direct database access should rarely be necessary outside of engineering, development, or troubleshooting.

---

# Revision History

| Date | Revision | Description |
| --- | --- | --- |
| 2026-07-03 | 0.4 | Completed the Hydro-History Browser with event annotation support, added the EC Reference History dashboard, documented rainfall/dilution context for EC calibration, and updated dashboard workflow documentation. |
| 2026-07-01 | 0.3 | Added Hydro-History browser enhancements including source-aware activity selection, operator notes for both maintenance and EC reference records, standalone field notes with optional date/location context, EC reference water temperature display, and updated workflow documentation. |
| 2026-06-28 | 0.2 | Reorganized document around dashboard functionality, operator workflows, event history, and long-term design. Removed implementation details that are documented in the Node-RED and Home Assistant READMEs. |

---

# Navigation

**Previous**

- [03 – Harvest & Waste Tracking](03-harvest-and-waste-tracking.md)

**Next**

- [05 – Nutrient Management & EC Control](05-nutrient-management-and-ec-control.md)

**Related Documentation**

- [00 – System Overview](00-system-overview.md)
- [01 – Database Design](01-database-design.md)
- [Node-RED README](../node-red/README.md)
- [Home Assistant Packages README](../home-assistant/packages/README.md)

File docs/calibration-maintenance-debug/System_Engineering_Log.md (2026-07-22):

# Hydroponics Engineering Issue Log
**Date:** 2026-07-04

> **Purpose**
>
> This is a working engineering log. Nothing in this document is considered
> permanent design documentation until the issue is fixed and verified.
> Items are intentionally recorded as observations, theories, bugs, and
> action items. Once verified, the permanent documentation will be updated.

---

## Test Objective

Validate the complete automatic fill cycle after changing the delay from 2 minutes to 30 minutes.

Test included:

- Auto-fill trigger
- 5-minute debounce
- 30-minute dwell
- Automatic fill
- Automatic nutrient dosing
- Notifications
- Event logging
- Inventory tracking
- Manual ESP Override dosing
- EC correction

---

## Successful Results

## PASS - Auto Fill Trigger

- Tank dropped below threshold.
- 5-minute debounce worked.
- Auto Fill Scheduled notification generated.

Status: ✅ VERIFIED

---

## PASS - 30 Minute Delay

- Fill started after approximately 30 minutes.

Status: ✅ VERIFIED

---

## PASS - Automatic Fill

- Fill started automatically.
- Fill stopped correctly.
- Approximately 9.85 gallons added.

Status: ✅ VERIFIED

---

## PASS - Flow Meter Calibration Verification

### Purpose

Verify that reverting the fill flow meter calibration back to **1690 pulses/gal**
corrected the fill volume reporting error discovered during the previous auto-fill.

### Previous Test (2026-06-28)

Tank Volume (start): 10.7 gal

Tank Volume (end): 20.4 gal

Database Record:

- Water Added: 11.37 gal
- Dose A: 114 mL
- Dose B: 114 mL

### Conclusion

Flow meter calibration was determined to be over-reporting the amount of water added.

A separate **1-gallon manual water addition** was performed and confirmed that the
tank volume calculation is reasonable. This isolated the issue to the flow meter
calibration rather than the tank volume calculation.

### Action - Investigate ESPHome Flow Meter Calibration

See:

- `esphome/hydroponics-patio-esp32.yaml`
  - Flow Meter Calibration comments dated **2026-06-28**

### Today's Verification (2026-07-04)

Tank Volume (start): 11.1 gal

Tank Target: 21.0 gal

Expected Fill: 9.9 gal

Flow Meter Recorded: 9.85 gal

Tank Volume (end): 20.6 gal

### Result

✅ **PASS**

The reverted **1690 pulses/gal** calibration produced a measured fill within **0.05 gallons** of the expected fill. The previous calibration issue is considered resolved.

Status: VERIFIED

---

## EC Calibration

During auto-fill validation, additional EC reference data was collected.

See:

`docs/calibration-maintenance-debug/EC_TDS_CALIBRATION_HISTORY.md`

Reason:

The automatic fill dose restored nutrients proportional to the water added but
did not restore the tank to the target EC of 2.0. A manual correction was
required to obtain another calibration reference point.

## Calibration History From This Test

| Time | Event | Tank | Probe | Handheld EC |
|---|---|---:|---:|---:|
| 09:10 | Before fill | 11.7 gal | 1.799 V | 1.70 |
| 12:59 | After auto fill | 20.6 gal | 1.752 V | 1.60 |
| 13:37 | Before correction | 20.6 gal | 1.774 V | 1.70 |
| 14:17 | After +50/+50 mL | 20.5 gal | 1.961 V | 2.00 |

---

## Decisions Made Today

- Maintenance Auto Dose remains disabled.
- Auto Fill controller successfully completed validation.
- Fill dosing remains proportional to gallons added until further evidence suggests otherwise.
- EC correction should continue using post-fill maintenance dosing.
- Permanent documentation will NOT be updated until all fixes are implemented and verified.

---

## Working Action List

## HIGH

- [ ] Repair Event History Dashboard
- [ ] Fix Auto Fill Logged notification values
- [ ] Fix Maintenance notification tank volume
- [ ] Determine inventory update sequence
- [ ] Redesign Maintenance Auto Dose controller
- [ ] Add Controller State indicator
- [ ] Investigate Manual ESP Override anomaly

## MEDIUM

- [ ] Fix duplicate notifications
- [ ] Improve dashboard status cards
- [ ] Improve Event Notes
- [ ] Improve event rendering by event type

---

## Notes

This document is intentionally a working engineering notebook.

Nothing contained here should be considered permanent design documentation until each issue has been fixed, tested, and verified.

---

## Issues Discovered

# ISSUE-001 - Event History Dashboard / Formatter

### Problem

The Browse for Event cards were using a generic formatter that displayed
irrelevant fields for different event types.

Examples:

- EC_REFERENCE displayed Fill 0.00 gal and Dose 0 mL.
- NOTE events displayed unrelated fill information.
- Event titles did not clearly identify the type of operation performed.

### Changes Made

- Added event-type-specific formatting in the Node-RED
  **Format Recent Activity** function.
- Updated `v_hydro_recent_activity` to expose `meter_value`
  and `meter_units` for EC reference events.
- EC_REFERENCE cards now match the EC Reference History display.
- NOTE events now display only note-related information.

### Enhancement Requested

Improve event titles to identify the operation performed rather than only
displaying the generic event type.

Examples:

Current:

```
#59 — DOSE
```

Preferred:

```
#59 — Auto Fill
#60 — Manual Fill
#61 — ESP-Override Dose
#62 — Auto Maintenance Dose
#63 — EC Reference
#64 — Field Note
```

The event title should immediately identify the workflow that created the
record while preserving the event number.

### Status

🟡 PARTIALLY COMPLETE

Formatting issues have been corrected.

Event title naming remains to be implemented.

---

# ISSUE-002 - Auto Fill Completion Notifications

Priority: HIGH

### Observed

The automatic fill completed successfully, but the completion notifications
contained inconsistent information.

### Notifications Received (Newest First)

#### Maintenance Cycle Complete

(Source: Node-RED Flow-1 Hydroponics Cycle Manager)

```
auto FILL completed

Water Added: 9.85 gal
Dose A: 98 mL
Dose B: 98 mL
System Volume: 11.1 gal
TDS: 1.800 → 1.751
```

Issues:

- Water added is correct.
- Dose A/B values are correct.
- **System Volume is incorrect.**
  - Reported: **11.1 gal**
  - Expected: **20.5–20.6 gal** (post-fill volume)

---

#### 🤖 Auto Fill Logged

```
9.85 gallons filled
Mode: Auto

Dose A: 0.0 mL
Dose B: 0.0 mL
```

Issues:

- Water added is correct.
- Dose values are incorrect.
- This notification may no longer provide useful information now that the
  Maintenance Cycle Complete notification contains more complete information.

---

#### 🤖 Auto Fill Scheduled

```
Tank is low (11.2 gal)...

Auto fill will begin...
```

This notification behaved as expected and should be retained.

### Current Interpretation

The fill itself executed correctly.

The problems appear to be in the notification data rather than the controller.

Evidence suggests different notifications are using different snapshots of the
controller state.

Examples:

- Water Added appears to be correct.
- Dose values are correct in one notification but zero in another.
- System Volume is using the pre-fill value instead of the final tank volume.

This suggests the notifications are being generated at different points in the
workflow or are reading different entities.

### Fill Cycle Entity Inventory

| Entity | Purpose | Current Status | Notes |
|---|---|---|---|
| sensor.outside_tank_gallons | Current calculated tank volume | ✅ Active | Used before and after fill. |
| sensor.outside_filtered_tank_gallons | Legacy filtered tank volume | ⚠ Investigate | Used last year when the scale was noisy. Current HX711 data appears stable enough that this may no longer be needed. |
| input_number.tank_full_target | Target full tank volume | ✅ Active | Used to determine fill target. |
| input_number.auto_fill_threshold_gallons | Auto-fill trigger threshold | ✅ Active | Starts 5-minute debounce. |
| input_number.outside_manual_fill_gallons | Requested fill amount | ✅ Active | Manual fill target. |
| sensor.hydroponics_patio_esp32_fill_gallons | ESP flow meter total during fill | ✅ Active | Resets after fill. Represents water added. |
| sensor.hydroponics_patio_esp32_last_fill_gallons | Last fill amount | ⚠ Unknown | Lost after ESP reboot. Candidate to replace with HA helper. |
| input_datetime.auto_fill_threshold_crossed_at | Low tank detected | ✅ Active | Used for debounce timing. |
| input_datetime.outside_tank_fill_started | Fill start timestamp | ✅ Active | Last updated 2026-07-04 12:39:07. |
| input_datetime.outside_tank_fill_stopped | Fill stop timestamp | ✅ Active | Last updated 2026-07-04 12:41:07. |
| sensor.outside_tank_last_fill_duration | Last fill duration | ✅ Active | Derived from timestamps. |
| automation.outside_tank_fill_log_and_notify_auto_only | Main Auto Fill workflow | ✅ Active | Primary automation under investigation. |
| automation.pre_fill_manual_dose_a_b_based_on_target_gallons | Pre-fill nutrient dose | ✅ Active | Runs before fill. |
| automation.esp_override_tank_fill_log | ESP Override fill logging | ✅ Active | Manual/ESP override workflow. |
| automation.outside_tank_fill_manual_logging | Manual fill logging | ✅ Active | Separate from Auto mode. |
| automation.cancel_auto_fill_on_mode_change | Cancel pending auto fill | ✅ Active | Cancels scheduled fill if mode changes. |
| input_datetime.tank_refill_completed | Legacy helper | ⚠ Investigate | Last updated 2025-07-13. Appears unused. |

### Observation

The current HX711 tank scale appears sufficiently stable for automatic fill control.

The existing 5-minute low-level debounce provides the necessary protection against transient level changes, reducing the need for a separately filtered tank volume sensor.

The continued need for `sensor.outside_filtered_tank_gallons` should be reevaluated after additional operational testing.

## Fill Cycle Model

The system uses four different gallon values that must not be confused.

1. Starting Tank Volume (`sensor.outside_tank_gallons`)
2. Target Tank Volume (`input_number.tank_full_target`)
3. Water Added (`sensor.hydroponics_patio_esp32_fill_gallons`)
4. Ending Tank Volume (`sensor.outside_tank_gallons` after fill)

Several notification and logging bugs discovered on 2026-07-04 were caused by mixing these values.

### Questions To Investigate

- [x] Which automation generates the **🤖 Auto Fill Logged** notification?
  - `automation.outside_tank_fill_log_and_notify_auto_only`

- [x] Which process generates the **Maintenance Cycle Complete** notification?
  - Node-RED Flow-1 Hydroponics Cycle Manager

- [x] Which process generated the bad legacy CSV row?
  - `automation.outside_tank_fill_log_and_notify_auto_only`

- [ ] Which entity/value supplies **System Volume** in the Node-RED completion notification?
  - Current evidence suggests it is using the pre-fill tank volume.

- [ ] Should Node-RED Flow-1 report both:
  - Starting Volume
  - Final Volume

- [ ] Are any remaining notifications using stale helper values?

### Fixes Applied

- Removed legacy **🤖 Auto Fill Logged** notification from
  `automation.outside_tank_fill_log_and_notify_auto_only`.

- Removed legacy CSV write to `notify.file_2`.

- Fill-stopped branch now only:
  - timestamps fill stop
  - resets `input_boolean.allow_auto_fill`

- Updated Node-RED Flow-1 completion notification.
  - FILL events now distinguish between:
    - Starting Volume
    - Calculated Final Volume
  - DOSE events continue to report System Volume.

### Verification

⏳ Pending next automatic fill cycle.

Expected notification:

auto FILL completed

Water Added: xx.xx gal
Dose A: xx mL
Dose B: xx mL
Starting Volume: xx.x gal
Calculated Final Volume: xx.x gal
TDS: x.xxx → x.xxx

### Remaining Problem

The next automatic fill must verify that the updated Node-RED notification now reports:

- Starting Volume
- Calculated Final Volume

instead of the misleading `System Volume`.

The larger remaining issue is that dashboard values sourced directly from ESPHome sensors are transient and are lost after ESP reboot/reflash.

Persistent “last completed cycle” values need to be stored in Home Assistant helpers and displayed through read-only template sensors.

Status: IMPLEMENTED - pending next fill verification

### ESPHome Helper Naming Fix

Validation passed.

Changed ESPHome post-fill helper writes to:

- `input_datetime.outside_tank_fill_stopped`
- `input_number.outside_tank_last_fill_gallons`

Status: IMPLEMENTED - pending next fill verification

### Verification - 2026-07-06 Short Auto Fill

Chronological test sequence:

1. EC reference before fill:
   - Time: 2026-07-06 08:33
   - EC: 1.70
   - Probe: 1.716 V
   - Tank: 17.8 gal
   - Temp: 67.2°F

2. Auto Fill Scheduled notification:
   - Tank low: 17.8 gal
   - Fill scheduled for 09:00
   - Notification worked, but wording should change from:
     `Turn Off input_boolean.allow_auto_fill`
     to:
     `Turn Off Auto Fill Gate`

3. Auto Fill - Auto Dose completed.

4. Node-RED completion notification reported:
   - Water Added: 4.28 gal
   - Dose A: 43 mL
   - Dose B: 43 mL
   - Starting Volume: 17.7 gal
   - Calculated Final Volume: 22.0 gal
   - TDS: 1.735 → 1.706

5. EC reference after fill:
   - Time: 2026-07-06 09:14
   - EC: 1.70
   - Probe: 1.753 V
   - Tank: 21.1 gal
   - Temp: 67.8°F
   - Note: After maintenance cycle complete on short autofill

### Validation Result

The stale **Auto Fill Logged** notification was successfully removed.

Node-RED notification now correctly distinguishes:

- Water Added
- Starting Volume
- Calculated Final Volume

The notification still needs terminology cleanup:

- Rename title from **Maintenance Cycle Complete**
  to **Auto Fill - Auto Dose Complete** when event type is `FILL`.

The calculated final volume was:

`17.7 + 4.28 = 22.0 gal`

Actual post-fill tank reading was:

`21.1 gal`

This difference should be noted but not treated as a failure yet because the tank scale may not have fully stabilized at notification time or the calculation uses pre-fill + flow-meter value rather than final tank weight.

### Dashboard Observations During 2026-07-06 Auto Fill

Screenshots captured the live dashboard state during the cycle.

Observed sequence:

1. Auto Fill Scheduled notification was correct, but wording should be updated:
   - Current: `turn Off the toggle: input_boolean.allow_auto_fill`
   - Preferred: `turn Off Auto Fill Gate`

2. Fill start timestamp updated correctly at fill start.

3. While filling, Fill Duration temporarily displayed a large negative value because:
   - fill start had updated to the current cycle,
   - fill stop still contained the previous cycle timestamp.

4. After fill completed:
   - Fill Ended updated correctly.
   - Fill Duration corrected to 0.8 min.
   - Gallons Measured showed 4.33 gal.
   - Last Fill Gallons showed 4.28 gal.

5. Auto dose sequence completed:
   - Dose A: 42.79 mL
   - Dose B: 42.79 mL
   - Pump A Runtime eventually showed 26.99 s.
   - Pump B Runtime eventually showed 26.00 s.
   - Last Dose A and Last Dose B updated to 7/6/2026 9:01 AM.

### Status

What was accomplished

Controller Modes

✅ Renamed operating modes to reflect actual behavior:
Auto Fill - Auto Dose
Manual Fill - Auto Dose
ESP-Override
✅ Updated dashboards.
✅ Updated conditional cards.
✅ Updated button-card colors.
✅ Updated Node-RED mode normalization with backward compatibility.

Flow-1 Cycle Manager

✅ Proper documentation added.
✅ Better separation of responsibilities.
✅ Notification titles now driven by controller mode and event type.

Notifications

✅ Removed obsolete Auto Fill notification.
✅ Removed legacy CSV write.
✅ Fixed fill summary to distinguish:
Water Added
Starting Volume
Calculated Final Volume

Persistence

✅ Last fill gallons now stored in a persistent HA helper.
✅ ESPHome helper names corrected.
✅ Identified the next phase of migrating "last completed cycle" values out of transient ESP sensors.

Documentation

✅ Node documentation standardized:
Purpose
Responsibilities (where appropriate)
Revision History
✅ ISSUE-002 is now largely verified with a real production fill.

### Related Files

Required:

- patio_controller.yaml
- patio_dosing_controls.yaml
- db_history_dashboard.yaml

As Needed:

- Home Assistant automations related to Auto Fill and Auto Dose
- Hydroponics_Cycle_Manager.json
- 05-nutrient-management-and-ec-control.md

### Components Affected

- ESPHome
- Home Assistant
- Node-RED
- MariaDB
- Dashboard
- Documentation

### Final Result

The notification redesign was successfully implemented and verified.

Legacy notifications and CSV logging were removed.

Node-RED now reports:

- Water Added
- Starting Volume
- Calculated Final Volume
- Dose A
- Dose B
- TDS Before/After

Remaining enhancements involving persistent dashboard state were moved to ISSUE-008.

### Status

**CLOSED – VERIFIED**

---

# ISSUE-003 - Inventory Synchronization

Priority: MEDIUM

Observed:

Inventory appeared unchanged after fill.

Later inventory reflected approximately:

98 mL Auto Fill
+
50 mL Manual Dose

Need to determine:

- when inventory updates
- who updates inventory
- why update timing is inconsistent

### Inventory Recovery

Container tare (matching container):
190 g

Cap:
6 g

Measured densities:

Part A
241 g / 200 mL = 1.205 g/mL

Part B
233 g / 200 mL = 1.165 g/mL

Gross weights:

Part A = 3500 g

Part B = 3300 g

Current inventory values require verification before permanent correction.

---

### Related Files

Required:

- batch_building.yaml
- patio_controller.yaml
- patio_dosing_controls.yaml
- db_history_dashboard.yaml

As Needed:

- Home Assistant automations related to Auto Fill and Auto Dose
- Hydroponics_Cycle_Manager.json
- 05-nutrient-management-and-ec-control.md

### Components Affected

- ESPHome
- Home Assistant
- Node-RED
- MariaDB
- Dashboard
- Documentation

Status: OPEN

---

# ISSUE-004 - ESP Override Manual Dose Anomaly

Priority: HIGH

### Observed

During an attempted manual ESP Override dose, the system entered an uncertain state.

Sequence:

- User intended to perform a 50 mL Part A manual dose.
- User pressed the **Motor Start/Stop** control instead of the **50 mL Dose** control.
- Dashboard timer continued counting.
- Pump state became questionable.
- Manual switch appeared responsive.
- Laptop/Wi-Fi issue occurred at the same time.
- System was powered down as a precaution.
- After recovery, a verified ESP Override dose was performed successfully.

### Notifications Observed

Unverified / anomaly event:

- ESP Override Dose A Logged
- Timestamp: `2026-07-04 01:12 PM`
- Duplicate notification received.
- Maintenance Cycle Complete also reported an ESP Override dose completion.
- Actual dose completion is uncertain.

Verified recovery event:

- ESP Override Dose A Logged
- Timestamp: `2026-07-04 01:58 PM`
- Dose A: 50.0 mL

- ESP Override Dose B Logged
- Timestamp: `2026-07-04 01:59 PM`
- Dose B: 50.0 mL

- Maintenance Cycle Complete
- System Volume: 20.6 gal
- TDS: 1.778 → 1.940

### Current Interpretation

The duplicate notification may not be a standalone notification bug.

It may have been caused by the same manual dosing anomaly:

- wrong dashboard control used,
- possible Wi-Fi/UI synchronization issue,
- interrupted dose sequence,
- system shutdown during uncertain state.

The important issue is not simply the duplicate notification. The issue is that the controller reported completion for a dose that may not have completed.

### Questions To Investigate

- [ ] Did the Motor Start/Stop control bypass the normal 50 mL dose script?
- [ ] Does the runtime counter continue if the pump is manually stopped?
- [ ] Can the ESPHome script report dose completion after interruption?
- [ ] Can Node-RED log a dose based on planned runtime instead of actual pump runtime?
- [ ] Did Home Assistant or Node-RED send duplicate notifications, or did the same event get emitted twice?
- [ ] Should manual pump start/stop be hidden or protected when dosing automation is active?

### Required Fix / Improvement

Manual pump controls must fail safe.

The system should not report a completed dose unless the dose script actually completed successfully.

If a manual dose is interrupted, the system should record it as:

```text
INTERRUPTED / UNKNOWN DOSE
```

Status: OPEN

---

# ISSUE-005 – Controller State Visibility

**Priority:** HIGH

### Current State

The dashboard does not yet accurately represent what the hydroponics controller
is doing at any given time.

Several independent Home Assistant automations, ESPHome scripts, timers, and
Node-RED flows may be active, but the dashboard currently provides only partial
or misleading status.

As a result, the operator cannot always quickly determine whether the controller
is:

* Idle
* Waiting
* Filling
* Dosing
* Mixing
* Complete
* Blocked
* Faulted

---

### Problems Observed

Examples encountered during development:

* Auto Dose card indicated **ON** while the automation itself was disabled.
* Controller appeared idle while actually waiting for the Auto Fill dwell period.
* Maintenance dosing was executing while the dashboard still showed **Ready**.
* Difficult to distinguish between:

  * Waiting for maintenance debounce
  * Waiting for scheduled fill
  * Waiting for nutrient mixing
  * Waiting before the next maintenance dose
* No indication that ESPHome was actively executing Pump A, Pump B, or a
  maintenance dose request.

---

### Design Goal

Create a single operator-facing controller state that accurately represents what
the hydroponics system is doing at any given time.

The dashboard should answer one question immediately:

> **What is the controller doing right now?**

without requiring the operator to inspect Home Assistant automations, ESPHome
logs, or Node-RED.

---

### Desired Visible States

Examples include:

* Idle
* Waiting for Low-Level Debounce
* Auto Fill Scheduled
* Filling
* Calculating Fill Dose
* Dosing Nutrient A
* Waiting Between Pumps
* Dosing Nutrient B
* Mixing
* Waiting for Maintenance Recheck
* Maintenance Dosing
* Cycle Complete
* Cancelled
* Blocked
* Fault
* Calibration Mode
* ESP-Override

The final state model may change during implementation.

---

### Engineering Decisions

The controller state design must preserve the existing separation of
responsibilities.

#### Home Assistant

Home Assistant owns:

* Operator configuration
* Maintenance dosing coordination
* Auto Fill coordination
* Dashboard presentation
* Controller state visibility
* Adjustable timing parameters

#### ESPHome

ESPHome remains responsible for:

* Physical pump outputs
* Fill solenoid control
* Pump sequencing
* Pump runtime
* Inter-pump delay
* Local execution safety gates

#### Node-RED

Node-RED remains responsible for:

* Completed-cycle logging
* Delayed post-mixing TDS capture
* Database writes
* Completion notifications

A configurable value should have one authoritative owner. Other components
should consume that value rather than defining duplicate independent settings.

---

### Configurable Timing Design

Four operating timing values were identified as operator-configurable.

#### Maintenance Debounce

Defines how long the maintenance-dose conditions must remain continuously valid
before a maintenance dose may begin.

**Default:** 5 minutes

**Owner:** `patio_dosing_controls.yaml`

#### Maintenance Mixing Time

Defines how long newly added nutrients are allowed to circulate before the
post-dose TDS value is evaluated.

This value may require adjustment if tank volume or circulation flow rates are
changed.

**Default:** 10 minutes

**Owner:** `patio_dosing_controls.yaml`

#### Next Maintenance Dose Offset

Defines the additional delay after the mixing period before another automatic
maintenance dose may begin.

**Default:** 60 seconds

**Owner:** `patio_dosing_controls.yaml`

#### Auto Fill Dwell

Defines how long the Auto Fill gate must remain continuously valid before an
automatic fill begins.

This is primarily a system-confidence delay and may be reduced as confidence in
the tank scale and fill controls improves.

**Default:** 30 minutes

**Owner:** `patio_system_constants.yaml`

The following execution timing values remain fixed implementation constants:

* Home Assistant to ESPHome request propagation delay: 2 seconds
* ESPHome Pump A to Pump B separation: 5 seconds

---

### Work Completed

#### Documentation

* Added Home Assistant package ownership guidance to the system overview.
* Added configurable maintenance timing design to the nutrient management
  documentation.
* Confirmed that engineering documents describe design intent while YAML and
  Node-RED files document implementation details.

#### Home Assistant Packages

Added the following helpers to `patio_dosing_controls.yaml`:

* `input_number.outside_maintenance_debounce_minutes`
* `input_number.outside_maintenance_mixing_minutes`
* `input_number.outside_maintenance_next_dose_offset_seconds`

Added the following helper to `patio_system_constants.yaml`:

* `input_number.outside_auto_fill_dwell_minutes`

All four helpers loaded successfully in Home Assistant.

#### Automation Logic

Updated the Outside TDS Maintenance Auto Dose automation to use:

* Configurable Maintenance Mixing Time
* Configurable Next Maintenance Dose Offset

Updated the Outside Maintenance Dose Due binary sensor to use:

* Configurable Maintenance Debounce

Updated the Auto Fill - Auto Dose automation to use:

* Configurable Auto Fill Dwell

#### Dashboard

Added the maintenance timing controls to the Auto-Dose Settings card.

Added the Auto Fill Dwell control to a separate Auto Fill Settings card.

Corrected the maintenance request button entity to:

```text
button.patio_hydroponics_outside_run_maintenance_dose_request
```

---

### Remaining Work

The timing configuration phase is complete.

The remaining ISSUE-005 work is to create the actual controller state machine
and dashboard state presentation.

Remaining tasks include:

* Define the authoritative controller-state entity.
* Track current maintenance cycle count.
* Display the active maintenance cycle as Cycle X of Y.
* Display the maintenance mixing countdown.
* Distinguish between:

  * Waiting for low TDS
  * Maintenance debounce
  * Maintenance dosing
  * Mixing
  * Waiting before the next dose
  * Completed
  * Disabled
  * Blocked
  * Fault
* Reflect active ESPHome pump and fill operation.
* Reflect Auto Fill dwell and scheduled fill state.
* Coordinate the configurable mixing time with the Node-RED delayed TDS capture.
* Update dashboard cards to use the new controller state.
* Perform one final supervised maintenance-dose validation.
* Close ISSUE-006 after delayed TDS-after readings are confirmed accurate.

---

### Related Files

Required:

* `patio_controller.yaml`
* `patio_dosing_controls.yaml`
* `patio_system_constants.yaml`
* `db_history_dashboard.yaml`

As Needed:

* Home Assistant automations related to Auto Fill and Auto Dose
* `Flow-1_Hydroponics_Cycle_Manager.json`
* `05-nutrient-management-and-ec-control.md`
* `00-system-overview.md`

---

### Components Affected

* ESPHome
* Home Assistant
* Node-RED
* MariaDB
* Dashboard
* Documentation

---

### Status

**OPEN – Timing Configuration Complete; Controller State Machine Pending**

---

# ISSUE-006 – Closed-Loop Nutrient Dosing Automation

**Priority:** HIGH

### Current Status

**Core implementation complete.**

The maintenance dosing architecture has been redesigned and validated.

The patio_controller now supports maintenance dosing as an additional command
path without requiring Home Assistant to change the Outside Control Mode.

The Home Assistant automation remains **disabled** while additional EC/TDS
correlation data is collected before allowing unattended maintenance dosing.

---

## Original Problem

The original maintenance dosing concept temporarily changed the global
Outside Control Mode to **ESP-Override** in order to operate the nutrient
pumps.

This interrupted Auto Fill ownership and could cancel an active or pending
automatic fill cycle.

That design has been retired.

---

## Final Architecture

Maintenance dosing is now implemented as a request into the existing
`patio_controller`.

Home Assistant is responsible only for requesting a maintenance dose.

The `patio_controller` remains the sole authority controlling all physical
outputs.

### Maintenance Dose Sequence

```text
HA detects low TDS voltage
        ↓
HA calculates proportional maintenance dose
        ↓
HA writes:
  outside_maintenance_dose_request_a_ml
  outside_maintenance_dose_request_b_ml
        ↓
HA presses:
  button.hydroponics_patio_esp32_run_maintenance_dose_request
        ↓
patio_controller validates all safety gates
        ↓
Pump A
        ↓
5-second dwell
        ↓
Pump B
        ↓
Node-RED logs completed cycle
        ↓
HA waits 10-minute mixing period
        ↓
HA evaluates whether another maintenance cycle is required
```

I also recommend changing the issue title itself from **"Maintenance Auto Dose"** to **"Closed-Loop Maintenance Dose Automation"** once you enable it. At that point, the architectural work (ISSUE-006) will be complete, and the remaining work will be about tuning the automatic control algorithm rather than implementing the feature.

### Related Files

Required:

- 01-database-design.md
- db_history_dashboard.yaml

As Needed:

- Hydroponics_Cycle_Manager.json
- Node-RED history logging flow
- maintenance_log table definition
- v_hydro_recent_activity view

### Components Affected

- ESPHome
- Home Assistant
- Node-RED
- MariaDB
- Dashboard
- Documentation

### Spawned ISSUE-011 for Additional TDS Meter install and system validation
---

# ISSUE-007 – History / Logging Improvements

**Priority:** MEDIUM

### Scope

Improve the usability and completeness of the Hydroponics history system.

### Logging Improvements

- Improve engineering field note entry.
- Display notes more cleanly in the history browser.
- Separate engineering notes from fill-specific information.
- Continue improving history browsing and filtering.

### History Display Improvements

- Include the year in timestamps.

Current:

Mon, Jul 6, 2:09 PM

Desired:

Mon, Jul 6, 2026, 2:09 PM

### Related Files

Required:

- 01-database-design.md
- db_history_dashboard.yaml

As Needed:

- Hydroponics_Cycle_Manager.json
- Node-RED history logging flow
- maintenance_log table definition
- v_hydro_recent_activity view

### Components Affected

- ESPHome
- Home Assistant
- Node-RED
- MariaDB
- Dashboard
- Documentation

### Status

OPEN

---

# ISSUE-008 – Cycle Persistence & Dashboard State

**Priority:** MEDIUM

### Scope

Improve dashboard behavior for completed cycles and controller restarts.

### Current Problems

ESPHome sensors represent only the current execution state.

After an ESP reboot or firmware update, several dashboard values revert to
their defaults because the controller has no knowledge of the previous cycle.

Observed examples:

- Last fill gallons
- Dose A amount
- Dose B amount
- Pump runtimes
- Fill duration
- Other cycle summary values

### Fill Duration Bug

During an active fill, the Fill Duration display should never calculate
against the stop timestamp from the previous fill.

If:

```text
fill_stopped < fill_started
```

display:

- Filling...
- Current elapsed time
- Unknown

instead of a negative duration.

### Design Direction

ESPHome should publish live execution data only.

Completed-cycle values should persist in Home Assistant helpers and be exposed
through read-only template sensors for dashboard use.

### Related Files

Required:

- 01-database-design.md
- db_history_dashboard.yaml

As Needed:

- Hydroponics_Cycle_Manager.json
- Node-RED history logging flow
- maintenance_log table definition
- v_hydro_recent_activity view

### Components Affected

- ESPHome
- Home Assistant
- Node-RED
- MariaDB
- Dashboard
- Documentation

### Status

OPEN

---

# ISSUE-009 – Refactor Nutrient Pump Execution Architecture and Secure ESP-Override Controls

**Status:** Active  
**Discovered:** 2026-07-07  
**Priority:** High  
**Dependencies:** Complete after ISSUE-006

---

## Purpose

Create one authoritative nutrient-pump execution architecture that separates
dose calculation from physical pump execution while preserving all required
Fill, Maintenance, Manual Dose, and ESP-Override functionality.

The refactor must eliminate unsafe or ambiguous operator paths that can energize
a nutrient pump without:

- a defined dose quantity,
- a calculated maximum runtime,
- automatic pump shutoff,
- dose accounting,
- controller-state visibility,
- and event logging.

Direct nutrient-pump relay switches must not remain exposed as normal operator
controls. Any retained direct relay control must be restricted to an explicitly
enabled service or maintenance mode and clearly identified as bypassing normal
dose execution safeguards.

This refactor will:

- reduce duplicated nutrient-pump execution code,
- provide one controlled execution path for measured doses,
- prevent accidental indefinite pump operation,
- maintain accurate nutrient totals and history,
- improve controller-state reporting,
- simplify future enhancements,
- and reduce inconsistencies between Fill, Maintenance, Manual Dose, and
  ESP-Override operation.

## Safety Requirement

A normal dashboard operator must not be able to directly latch Nutrient Pump A
or Nutrient Pump B ON.

All normal nutrient additions must be initiated as a requested quantity in mL
and executed by a bounded ESPHome dosing script.

The dosing script must:

1. Validate the requested quantity.
2. Convert the quantity to pump runtime.
3. Apply a configured maximum dose and maximum runtime.
4. Energize the selected pump.
5. Automatically de-energize the pump when the runtime expires.
6. Update the measured-dose and runtime entities.
7. Expose execution state to the controller state machine.
8. Produce sufficient information for event logging.

Any direct relay control retained for diagnostics must:

- be hidden from the normal operating dashboard,
- require an explicit service-mode enable,
- use momentary or time-limited execution rather than an indefinite latch,
- display a clear warning,
- and automatically return the pump to OFF.

## 2026-07-22 Safety Incident

During a manual EC correction, the operator intended to run the controlled
10 mL Nutrient B dose command but instead enabled the adjacent raw Pump B
switch.

Pump B remained energized for approximately 12 seconds until manually turned
off.

The raw relay path:

- did not use the requested 10 mL quantity,
- did not automatically stop,
- did not update the expected dose accounting,
- and could have caused a substantially larger overdose if not noticed.

A compensating second 10 mL Nutrient A dose was then performed because the
actual Nutrient B quantity was uncertain.

This incident confirms that raw nutrient-pump switches must not be presented as
normal operator controls.
---

## Current Architecture

Each dosing mode currently performs both:

- Dose calculation
- Pump execution

For example:

## Fill Dose

```text
Determine gallons added
Calculate nutrient mL
Calculate pump runtime
Publish runtime sensors
Turn on pump
```

## ESP-Override Dose

```text
Read operator-entered mL
Calculate pump runtime
Publish runtime sensors
Turn on pump
```

As a result, much of the pump execution logic is duplicated between scripts.

---

## Proposed Architecture

Separate nutrient dosing into two logical layers.

## Layer 1 – Dose Source

Responsible only for determining the requested nutrient amount.

### Fill Dose

```text
Gallons Added
        │
        ▼
Requested Dose (mL)
```

### Maintenance Dose

```text
Maintenance Request
        │
        ▼
Requested Dose (mL)
```

### ESP-Override

```text
Manual A Request
Manual B Request
```

Layer 1 should **never** calculate pump runtimes.

---

## Layer 2 – Pump Execution

Responsible only for executing a requested nutrient dose.

Responsibilities:

- Apply pump calibration
- Calculate runtime
- Publish dose sensors
- Publish runtime sensors
- Set running flags
- Turn on physical pump

Pump execution should not know whether the request originated from:

- Fill replacement
- Maintenance dosing
- ESP-Override
- Future automation

Its only responsibility is:

```text
Dose this pump X milliliters.
```

---

## Pump Calibration

Pump calibration belongs exclusively within the pump execution layer.

Each pump independently converts:

```text
Runtime (seconds) =
Requested Dose (mL)
-------------------
Pump Calibration (mL/sec)
```

Pump A and Pump B intentionally remain independent because their calibrated
flow rates may differ.

---

## Equal-Dose Modes

The following operating modes always request identical nutrient amounts for
both nutrient pumps:

- Auto Fill - Auto Dose
- Manual Fill - Auto Dose
- Maintenance Dose

These modes should calculate a single requested dose value and supply that
same value to both pump execution routines.

---

## Independent-Dose Mode

ESP-Override intentionally allows different requested amounts.

```text
Pump A = Manual A Dose

Pump B = Manual B Dose
```

Because of this, ESP-Override remains a special case.

---

## Benefits

This refactor will:

- Eliminate duplicated runtime calculations.
- Centralize pump calibration logic.
- Improve long-term maintainability.
- Simplify future maintenance dose implementation.
- Reduce future regression risk.
- Keep Fill, Maintenance, and ESP-Override execution consistent.

---

## Design Philosophy

The controller should determine **how much** nutrient is required.

The pump should determine **how long** it must run.

Separating these responsibilities improves readability, testing, and future
extensibility while minimizing duplicated code.

---

## Proposed Script Organization

```text
Fill Dose A
        │
        ▼
Execute Pump A

Fill Dose B
        │
        ▼
Execute Pump B

Maintenance Dose A
        │
        ▼
Execute Pump A

Maintenance Dose B
        │
        ▼
Execute Pump B

ESP-Override Dose A
        │
        ▼
Execute Pump A

ESP-Override Dose B
        │
        ▼
Execute Pump B
```

The pump execution routines become the only location responsible for
calibration and runtime calculations.

 |

---

# ISSUE-010 – Improve Field Note Entry

**Priority:** LOW

### Current Status

Functional, but the Home Assistant user interface makes entering engineering field notes cumbersome.

### Current Behavior

Field notes are stored correctly in `maintenance_log` as `NOTE` events.

The current workflow uses:

- `input_text.hydro_history_field_note`
- Browser Mod popup
- Date selector
- Location selector
- Save button

Although the popup improves the workflow, the built-in Home Assistant `input_text` editor only provides a single-line text entry field.

Longer engineering observations require horizontal scrolling, making them difficult to review and edit before saving.

### Desired Behavior

Provide a larger text entry experience suitable for engineering field observations.

Desired capabilities include:

- Multi-line text entry
- Comfortable editing of longer notes
- Ability to review the entire note before saving
- Maintain the existing Browser Mod popup workflow

### Possible Solutions

Evaluate one or more of the following:

- Replace the built-in `input_text` editor with a custom Lovelace textarea component.
- Use a Browser Mod popup containing a custom card that supports multi-line text entry.
- Develop a dedicated Field Note popup modeled after the Measure EC workflow.
- Investigate alternative Home Assistant UI components that provide a true textarea experience.

### Database Impact

None.

`maintenance_log` already supports the required note length.

This issue is strictly a Home Assistant user interface improvement.

### Status

Deferred until higher-priority hydroponics control and EC calibration work is complete.

# ISSUE-011 Voltge Measurements not working for Auto Dose. Add 2nd DFRobot Gravity TDS Meter

---

#@ Related Refactoring (2026-07)

While implementing the pump execution refactor, the nutrient measurement
architecture was also modernized to support multiple analog probe channels and
improve long-term maintainability.

The following engineering changes were completed:

### Dual Analog Probe Architecture

The controller now supports two independent analog probe channels.

Current assignments:

- A0 – Original KEYESTUDIO analog probe
- A1 – DFRobot Gravity analog probe

Future analog channels remain available for additional sensors.

### Engineering Measurement Model

Legacy "TDS" field names were retired from the engineering data model.

Maintenance events now store:

- A0 Raw Before
- A0 Filtered Before
- A1 Raw Before
- A1 Filtered Before
- A0 Raw After
- A0 Filtered After
- A1 Raw After
- A1 Filtered After

EC reference records now store synchronized snapshots of:

- A0 Raw
- A0 Filtered
- A1 Raw
- A1 Filtered

The handheld EC meter remains the engineering reference standard.

### Database Refactoring

Updated:

- maintenance_log
- hydro_tds_reference_reading
- v_hydro_recent_activity

Legacy probe_voltage and TDS voltage fields were removed in favor of explicit
A0/A1 engineering measurements.

### Node-RED

History Browser and Cycle Manager were updated to use the new engineering
measurement model.

Operator-facing history cards intentionally display filtered voltages while raw
measurements remain stored for engineering analysis and future calibration.

### Current Status

The engineering measurement migration has been verified through:

- Auto Fill
- Auto Fill + Auto Dose
- Manual EC Reference
- History Browser
- Completion Notifications
- MariaDB logging

Remaining work is limited to EC calibration and future control-model
improvements.

---

---

## Revision History

| Date | Author | Description |
|---|---|---|
| 2026-07-22 | GAL | ISSUE-011 Added dual-probe engineering measurement architecture, A0/A1 schema migration, and logging refactor summary.
| 2026-07-07 | GAL | Initial architecture proposal.

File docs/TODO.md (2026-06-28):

# TODO

## Nutrient Stock Solution Inventory

- Add empty container weight and full container weight for Part A and Part B stock solution containers.
- Allow periodic manual container weight entry.
- Calculate remaining stock solution volume from current weight.
- Use remaining volume to estimate doses remaining and days remaining.
- Possible future upgrade: load-cell monitoring for Part A and Part B containers.

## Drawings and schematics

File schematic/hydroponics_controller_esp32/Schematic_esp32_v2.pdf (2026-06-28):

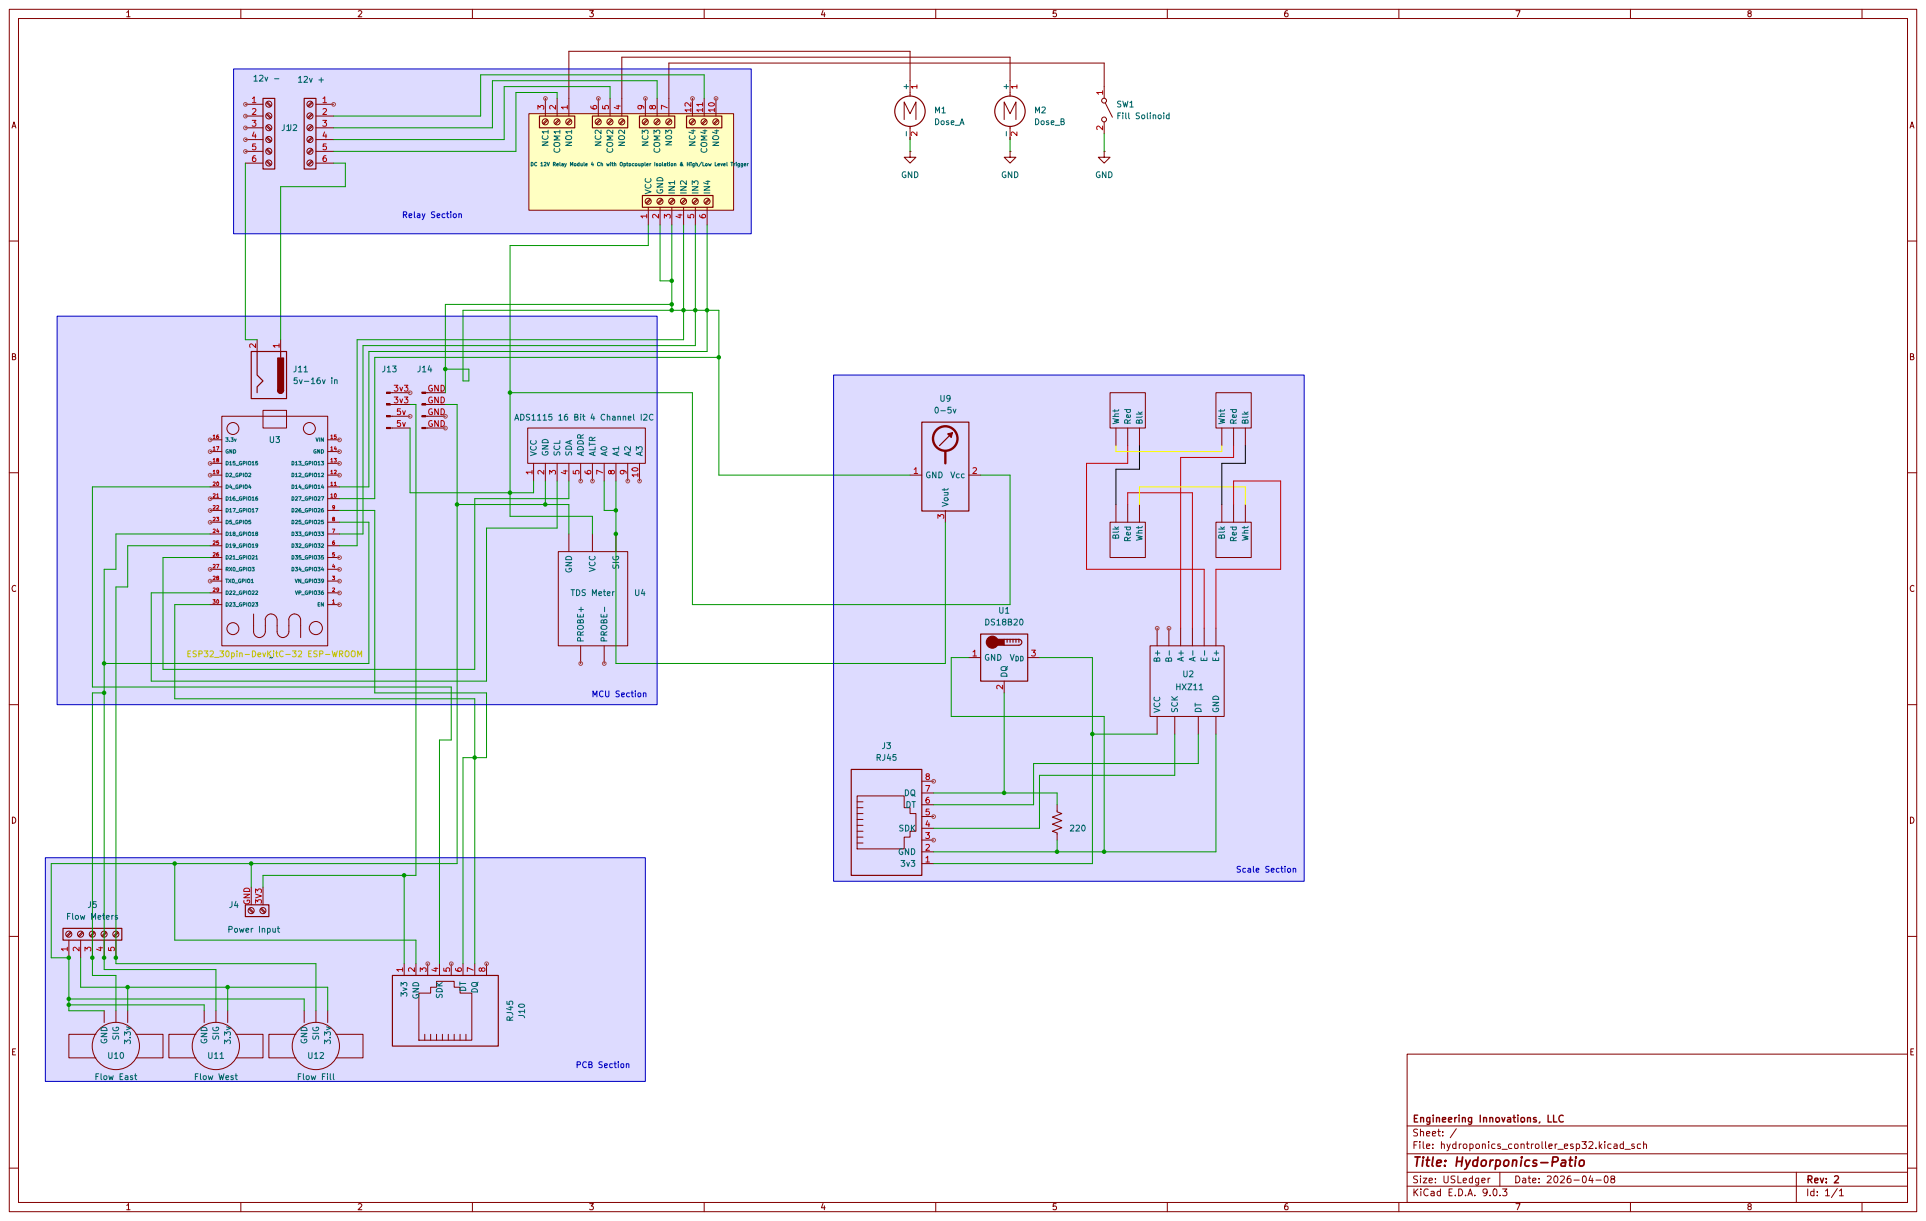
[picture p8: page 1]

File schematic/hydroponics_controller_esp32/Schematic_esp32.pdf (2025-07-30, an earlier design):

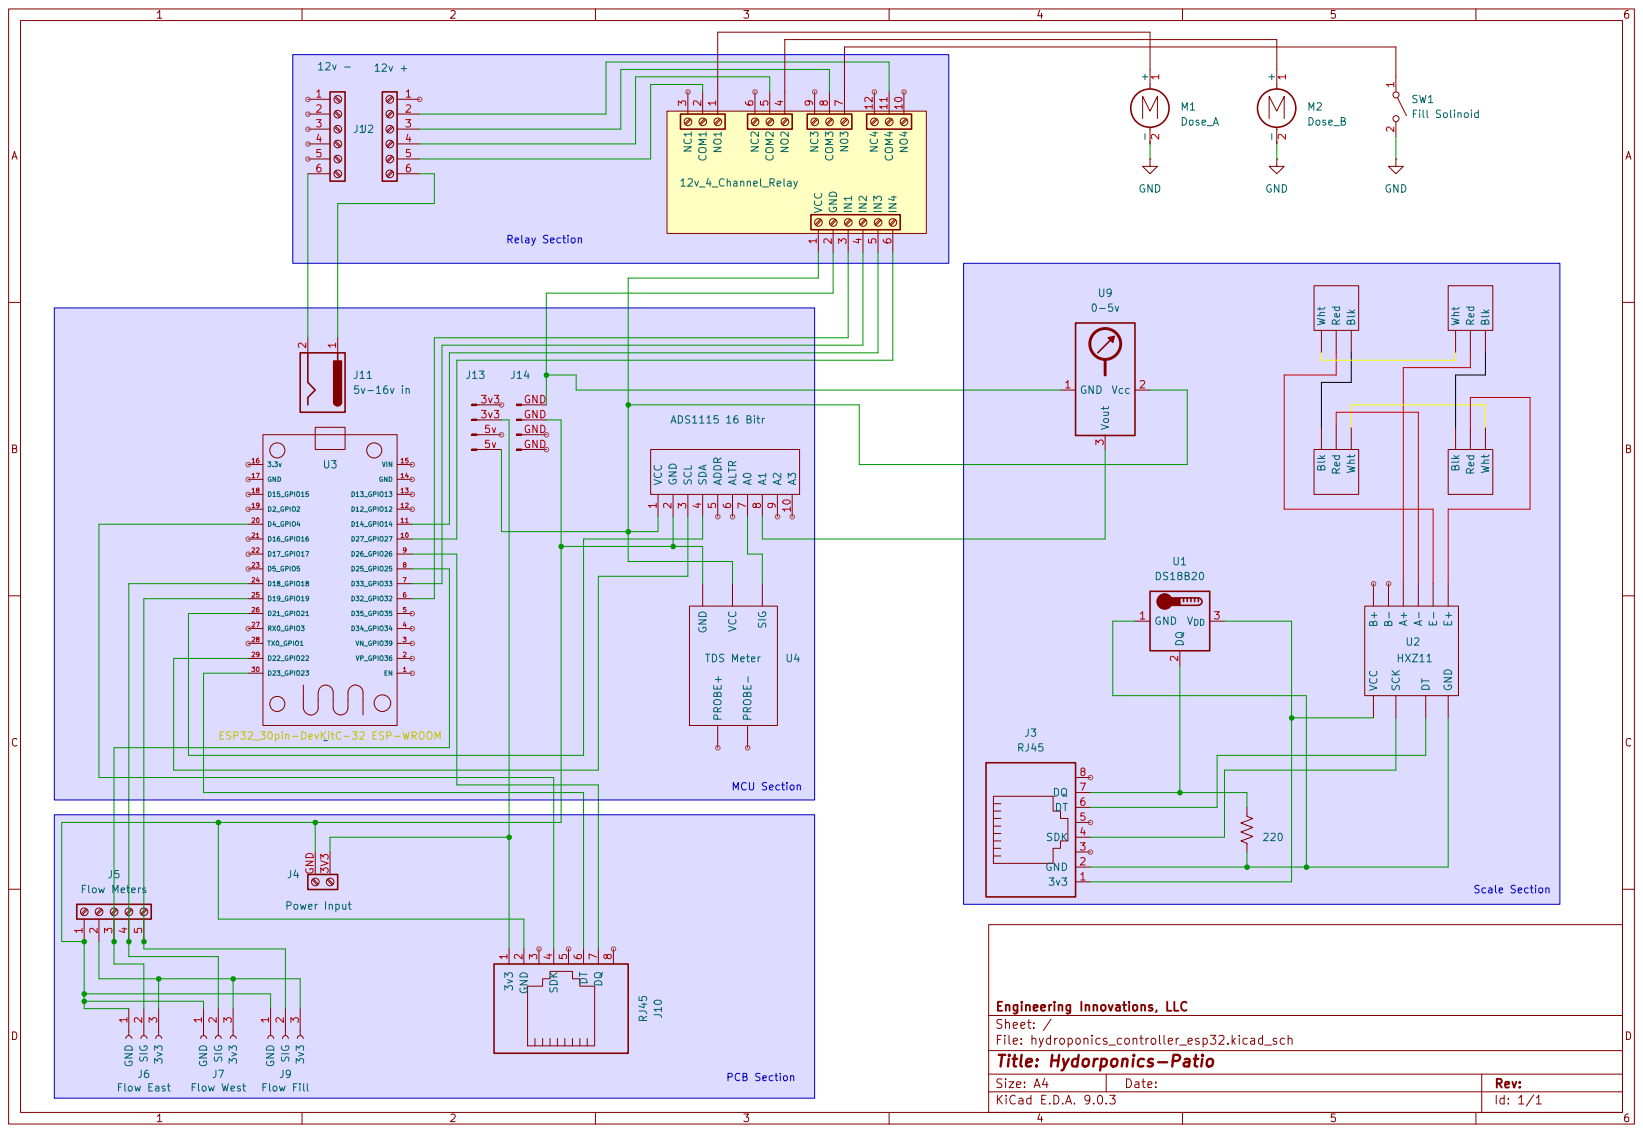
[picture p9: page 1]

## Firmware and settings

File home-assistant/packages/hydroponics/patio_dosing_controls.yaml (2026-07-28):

# ==============================================================================
# Package: \config\packages\hydroponics\patio_dosing_controls.yaml

# Project: Hydroponics Veggie Garden
# Author: Greg Liebig

#
# Purpose
# -------
# Provides helper entities, calculated sensors, inventory tracking, safety
# interlocks, and status sensors used by the outside hydroponic dosing system.
#
# This package does NOT perform automatic dosing.  All automations remain in
# the Home Assistant UI to preserve Automation Traces for troubleshooting.
#
# ------------------------------------------------------------------------------
# Automatic Maintenance Dosing
# ------------------------------------------------------------------------------
#
# UI Automation:
#   Outside TDS Maintenance Auto Dose
#
# Purpose:
#   Maintain minimum nutrient concentration while the outside hydroponic system
#   is circulating. This is independent of the automatic refill controller.
#
# Control Strategy:
#
#   Production Operation
#   --------------------
#   • Current production auto-dose logic uses raw TDS probe voltage.
#   • Calculates a step dose from:
#
#         Tank Volume × mL per Gallon
#
#   • Doses equal amounts of Nutrient A and Nutrient B.
#   • Waits for the configurable maintenance mixing period.
#   • Rechecks probe voltage after mixing.
#   • Applies a configurable offset before another maintenance dose may begin.
#   • Repeats until:
#       - Minimum voltage threshold is restored, OR
#       - Maximum dose cycles are reached.
#
#   Engineering & Calibration
#   -------------------------
#   • Outside Estimated EC provides a live engineering estimate of
#     reservoir EC for dashboard monitoring and comparison against
#     handheld EC reference measurements.
#   • Estimated EC is NOT currently used for automatic dosing.
#   • Each EC reference measurement stores:
#       - Estimated EC snapshot
#       - Raw probe voltage
#       - Handheld EC measurement
#       - Rainfall and estimated dilution
#   • EC model performance is tracked using the calculated EC error
#     (handheld EC − Estimated EC).
#   • Historical reference data is used to improve future Estimated
#     EC calibration models.
#
# Operating Range
# ----------------
#   Auto Dose Trigger      ≈ 1.80 V (configurable)
#   Normal Operating Band  1.80–2.00 V
#   Hard Stop              2.10 V
#   Sensor Upper Limit     ≈ 2.40 V
#
# Safety Interlocks
# -----------------
# Auto dosing is inhibited when:
#
#   • Auto Dose Enabled = OFF
#   • Calibration Mode = ON
#   • Outside System = OFF
#   • Control Mode ≠ Auto
#   • Automatic refill/dosing cycle is active
#   • Fill solenoid is active
#   • Nutrient Pump A or B is already running
#   • Mixing is not confirmed
#   • Tank volume is invalid or below minimum
#   • Nutrient inventory is below configured threshold
#   • Nutrient inventory is unknown/unavailable
#   • Step dose computes to zero
#   • Hard-stop voltage has been reached
#
# Logging
# -------
# Every maintenance dose is written by Node-RED to:
#
#     maintenance_log
#
# including:
#
#   • Timestamp
#   • Tank volume
#   • Dose A/B
#   • TDS before
#   • TDS after
#   • Operating mode
#
# This historical data will eventually be used to improve dosing efficiency.
#
# ------------------------------------------------------------------------------
# Notes
# ------------------------------------------------------------------------------
#
# • Entities/helpers live in YAML for documentation and version control.
# • Automations remain in the UI for Trace support.
# • Suggested Dose sensors are informational only.
# • Capacities come from patio_system_constants.yaml.
# • Target TDS helpers are defined in patio_system_constants.yaml.
# • Maintenance dose events are logged to maintenance_log.
# • Handheld EC reference measurements are logged to
#   hydro_tds_reference_reading for engineering analysis and
#   Estimated EC model development.
#
# Revision History
# ----------------
# 2026-07-12  GAL  Expanded the EC reference engineering workflow.
#                  Added Estimated EC snapshot storage with each
#                  handheld EC reference measurement, rainfall
#                  baseline tracking, EC model error (ec_error)
#                  analysis, and Home Assistant engineering history
#                  dashboard support. These changes establish the
#                  long-term calibration dataset for future
#                  temperature- and rainfall-compensated Estimated
#                  EC models.
# 2026-07-10  GAL  ISSUE-005: Added configurable maintenance debounce,
#                  mixing time, and next-dose offset helpers. These helpers
#                  centralize operator-adjustable timing values; active
#                  automations and Node-RED will be updated separately.
# 2026-07-03  GAL  Added rainfall/dilution context to EC reference workflow.
#                  Rain total, rain since last EC reference, and estimated
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

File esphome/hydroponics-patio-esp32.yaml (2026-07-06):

#==============================================================================
# hydroponics-patio-esp32.yaml
#
# Project: Hydroponics Veggie Garden
# Controller: ESP32 DevKit
#
# Purpose:
#   Controls the outside hydroponics system including:
#     • Tank fill control
#     • Nutrient dosing (Auto / Manual / ESP-Override)
#     • HX711 tank scale
#     • Flow meter measurement
#     • ADS1115 EC/TDS measurement
#     • Home Assistant state synchronization
#
# Revision History
#
# 2026-07-05  GAL
#   Fixed Home Assistant helper naming for persistent fill-cycle data.
#   Updated ESPHome post-fill service calls to use:
#     • input_datetime.outside_tank_fill_stopped
#     • input_number.outside_tank_last_fill_gallons
#   Enables preservation of last completed fill information across ESP restarts.
#
# 2025-08-04  GAL
#   Fixed ESP-Override dosing interval.
#   Removed hard top-off logic.
#
# 2025-08-03  GAL
#   Standardized dosing sensor IDs.
#
# 2025-08-01  GAL
#   Added dosing history sensors.
#
# 2025-07-29  GAL
#   Added inline documentation during controller debugging.
#   Verified stable operation.
#
# 2025-07-26  GAL
#   Converted controller from D1 Mini to ESP32.
#
# 2025-07-15  GAL
#   Removed tank gallon calculation from ESPHome.
#   Moved tank volume calculation to Home Assistant.
#
# 2025-07-13  GAL
#   Removed temporary tare button.
#
# 2025-07-12  GAL
#   Rebuilt HX711 tank scale.
#   Added temporary tare button.
#
# 2023-06-16  GAL
#   Initial controller created.
#==============================================================================

esphome:
  name: hydroponics-patio-esp32
  friendly_name: hydroponics-outside

  on_boot:
    priority: -200  # Run as early as possible
    then:
      - output.turn_off: gpio_nutrient_pump_a
      - output.turn_off: gpio_nutrient_pump_b
      - output.turn_off: gpio_water_fill_solenoid
      - lambda: |-
          id(dose_a_ml_ESP) = 0.0;
          id(dose_a_ml).publish_state(0.0);

          id(dose_b_ml_ESP) = 0.0;
          id(dose_b_ml).publish_state(0.0);

esp32:
  board: esp32dev
  framework:
    type: esp-idf

# Dosing pump timing and reporting revised block 25-08-03
# This structure cleanly separates timers from published values.
# The runtime sensors will be updated only when pump turns off.
# The dose amount is stored alongside the runtime, making it easy to confirm dose consistency.
# Home Assistant will have clear state: pump ran for X seconds and dispensed Y mL.
globals:
  # ⏱ Runtime timer for Pump A (starts on turn_on, stops on turn_off)
  - id: pump_a_start_millis
    type: uint32_t
    restore_value: no
    initial_value: '0'

  # ⏱ Final runtime for Pump A (in seconds, published to HA)
  - id: pump_a_runtime_ESP
    type: float
    restore_value: no
    initial_value: '0.0'

  # 🧴 Dose amount for Pump A (in mL, published to HA)
  - id: dose_a_ml_ESP
    type: float
    restore_value: no
    initial_value: '0.0'

  # Flag to track if Pump A is currently running (prevents early shutoff) 25-08-03
  - id: pump_a_running
    type: bool
    restore_value: no
    initial_value: 'false'

  # Create a dwell timer to ensure Pump B waits 5 sec before starting 25-08-03
  - id: dwell_timer
    type: uint32_t
    restore_value: no
    initial_value: '0'

  # Flag to check for pump B to run 25-08-03
  - id: pump_b_waiting
    type: bool
    restore_value: no
    initial_value: 'false'

  # Flag to track if Pump B is currently running (prevents early shutoff) 25-08-03
  - id: pump_b_running
    type: bool
    restore_value: no
    initial_value: 'false'

  # ⏱ Runtime timer for Pump B
  - id: pump_b_start_millis
    type: uint32_t
    restore_value: no
    initial_value: '0'

  # ⏱ Final runtime for Pump B
  - id: pump_b_runtime_ESP
    type: float
    restore_value: no
    initial_value: '0.0'

  # 🧴 Dose amount for Pump B
  - id: dose_b_ml_ESP
    type: float
    restore_value: no
    initial_value: '0.0'

  # 💧 Last fill amount in gallons (after manual fill)
  - id: last_fill_gallons_ESP
    type: float
    restore_value: no
    initial_value: '0.0'

  # ⏱ Fill cycle start timestamp (millis)
  - id: fill_start_time
    type: uint32_t
    restore_value: no
    initial_value: '0'

  # 🚰 Fill state (0 = IDLE, 1 = RUNNING, 2 = COMPLETE)
  - id: fill_state
    type: int
    restore_value: no
    initial_value: '0'


# Enable logging
logger:
  level: VERBOSE
  logs:
    sensor: WARN
    ads1115.sensor: WARN
    pulse_counter: WARN
    hx711: WARN
    dallas.sensor: WARN
    component: WARN
    main: DEBUG
    manual_fill: DEBUG

# Enable Home Assistant API
api:

ota:
  - platform: esphome  # Your existing OTA method
  - platform: web_server  # Add this for web-based OTA uploads

wifi:
  ssid: !secret wifi_ssid
  password: !secret wifi_password

  # Enable fallback hotspot (captive portal) in case wifi connection fails
  ap:
    ssid: "Hydroponics-Patio-Esp32"
    password: "9zpm8sHTAuuT"

captive_portal:
    
web_server:
  port: 80
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

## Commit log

2025-07-15 Update README.md
    Revised template sensor yaml
2025-07-16 Added voltage divider image
2025-07-16 Added voltage divider doc
2025-07-16 Update voltage_divider_explained.md
    Added checking voltages prior to connecting to micro controller
2025-07-16 Corrected voltage divider diagram
2025-07-16 created folder structure and esp32 support. Added improved template.yaml calibration sensor
2025-07-17 Updated template sensor for calibration
2025-07-17 updated README for calibration template changes
2025-07-30 after testing and updating entities.
    [Controller_Project_BOM.csv, hydroponics_controller_esp32.kicad_pcb, hydroponics_controller_esp32.kicad_sch]
2025-07-30 Created Schematic PDF
    [hydroponics_controller_esp32.kicad_sch]
2026-06-28 Hydroponics project architecture redesign
    - Reorganized Home Assistant packages
    - Added Node-RED workflow exports
    - Added SQL schema
    - Added engineering documentation
    - Added project design documents
    - Updated ESPHome controller
    - Updated KiCad schematic
    - Replaced nutrient mixing documentation
    [ESP32_Pin_Assignments_for_KiCad.xlsx, hydroponics_controller_esp32.kicad_sch, patio_controller.yaml]
2026-06-29 History Dashboard Phase 1 – End-to-end database readback operational.
2026-07-01 Document Hydro-History browser operator annotation workflow
    - Document history navigation (single-step and page navigation)
    - Document event selection and operator note editing workflow
    - Update Hydro-History browser status and current capabilities
    - Remove obsolete planned features now implemented
    - Update dashboard design documentation for event annotation
    - Refresh Node-RED flow inventory and change log
2026-07-01 Complete Hydro-History application and EC reference integration
    Completed the Hydro-History application and supporting database workflows.
    Database
    - Added operator_note support to hydro_tds_reference_reading.
    - Updated v_hydro_recent_activity for multi-source history browsing.
    - Added EC reference water temperature support.
    Node-RED
    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
2026-07-03 Standardized Package files for hydro
    [hydroponics_controller_esp32.kicad_sch, patio_controller.yaml]
2026-07-03 Added rain capture to TDS EC Check to get data for rain dilution for eventual calibration
2026-07-03 feat: add EC reference history dashboard and calibration workflow
    Implemented a dedicated EC Reference History dashboard integrated with the Hydro-History Browser.
    Highlights:
    - Added Node-RED EC Reference History query branch.
    - Published formatted EC reference history to MQTT.
    - Added Home Assistant MQTT sensor and Markdown dashboard card.
    - Added rainfall and estimated dilution context to EC reference history.
    - Added operator note support for engineering observations.
    - Improved formatting for null values in historical records.
    - Updated dashboard history design documentation to reflect production implementation.
    - Corrected ADS1115 hardware configuration by powering the ADC from the 3.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
2026-07-06 Hydroponics: Begin persistent fill-cycle state architecture
    - Removed legacy Auto Fill notification and CSV logging
    - Simplified Auto Fill completion automation
    - Fixed ESPHome helper naming (outside_tank_* entities)
    - Added persistent last-fill gallons helper
    - Added read-only controller display sensors
    - Updated Flow-1 notification to report starting and final fill volumes
    - Reorganized controller dashboard terminology
    - Added engineering log for 2026-07-04 validation and debugging
    [hydroponics_controller_esp32.kicad_sch, patio_controller.yaml]
2026-07-07 Hydroponics: Review HA automations and refine nutrient management architecture
    Completed a comprehensive review of all Home Assistant automations related to
    the outside hydroponics controller.
    Automation cleanup:
    - Standardized controller mode names:
    • Auto Fill - Auto Dose
    • Manual Fill - Auto Dose
    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
2026-07-17 Copied all package yaml files from current HA system to this project and updated weather package for rainfall as a backup
    [patio_controller.yaml]
2026-07-22 Refactor engineering measurement model and history system
    Implemented the new dual-probe engineering measurement architecture and
    updated the history pipeline to support synchronized A0/A1 analog voltage
    measurements throughout the hydroponics system.
    - Refactored maintenance_log and EC reference schema documentation.
    - Replaced legacy single-probe terminology with A0/A1 raw and filtered
    voltage measurements.
    - Renamed Node-RED TDS Reference workflow to EC Reference.
    - Updated Cycle Manager and History Browser for new engineering fields.
    - Updated v_hydro_recent_activity to expose normalized engineering data.
    - Improved Auto Fill/FILL event rendering and history formatting.
    -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
2026-07-25 copied all current hydroponics yaml files from active server to project to ensure consistency
2026-07-28 Finished replacement of production nutrients with backup nutrients. next will be building new batches
    [batch_building.yaml, patio_dosing_controls.yaml, patio_system_constants.yaml]
2026-07-30 ISSUE-012 Added Dual TDS Probe Baseline Drift Investigation.
